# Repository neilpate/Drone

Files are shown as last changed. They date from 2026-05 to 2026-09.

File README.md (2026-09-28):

# Drone



A learning project: build a quadcopter from scratch — own hardware, own firmware, no existing flight stack.

The drone is the artefact; understanding the whole stack end-to-end is the deliverable.

## What we're building

- **Platform:** BBC micro:bit v2 (nRF52833) for Phases 1–3; custom nRF5340 PCBA for Phases 4–5.
- **Language:** Rust (`no_std`, `embassy-nrf`) on the firmware; Rust on the PC-side ground-station application too.
- **IMU:** ICM-42688-P on SPI (external; micro:bit's onboard sensor has no gyro).
- **Airframe:** quadcopter.
- **Flight stack:** rolling our own — no PX4 / ArduPilot.

See [`doc/00-vision.md`](doc/00-vision.md) for the full vision and the phased milestone plan.

## Status

**Phase 2 (advanced prototyping) in progress.** The whole stack runs on hardware. The drone has made **first free flights** — brief untethered, self-levelling hops on its own battery under closed-loop control — with telemetry over a two-hop radio link and PID gains **tuned live from the ground station and now persisted to flash** ([ADR 0025](doc/decisions/0025-persist-control-parameters-flash.md)): tune, save, power-cycle, and the gains survive.

- **Round trip, ~100 Hz, ~25–30 ms.** The `groundstation` app sends four-axis pilot commands (sliders or a gamepad) over USB-CDC to a remote micro:bit, which relays to the drone over IEEE 802.15.4 ([ADR 0014](doc/decisions/0014-radio-protocol-ieee802154.md)). Telemetry returns the same path as a high/low-rate split frame ([ADR 0027](doc/decisions/0027-split-telemetry-high-low-rate.md)), postcard + COBS framed, every buffer sized at compile time from the shared types.
- **Firmware — an Embassy task graph.** A **supervisor** failsafe ([ADR 0017](doc/decisions/0017-supervisor-failsafe-state-machine.md)) is the sole publisher of motor commands: a five-state machine with a stick arm/disarm gesture, idle auto-disarm, and loss-of-link detection within ~100 ms.
- **Sense → estimate → control.** The ICM-42688-P IMU ([ADR 0003](doc/decisions/0003-imu-icm42688-spi.md)) is read over SPI at 1 kHz; a complementary filter ([ADR 0022](doc/decisions/0022-attitude-estimation-complementary-filter.md)) gives a roll/pitch estimate; a single-loop **angle-mode PID** ([ADR 0024](doc/decisions/0024-control-law-angle-mode-pd.md)) mixes it and the pilot command into a four-motor demand. IMU zeroing is re-runnable from the ground station; every gain is a runtime message, saveable to flash.
- **Actuation + ESC telemetry.** **DShot300** drives a 4-in-1 AM32 ESC ([parts list](hardware/electrical/parts-list.md)); each ESC's **KISS serial telemetry** — RPM, pack voltage, temperature — is read back over an idle-framed UART and logged.
- **Discipline.** Frames, signs and command newtypes are fixed in [ADR 0021](doc/decisions/0021-coordinate-frames-and-command-semantics.md); the pure logic (filter, controller, supervisor, wire types) is host-tested in `firmware-drone-core`.

The ground station plots and logs every signal live, times the round trip, pushes and saves PID gains, shows a live 3D view of the drone's attitude, and pairs with an offline `analyze` tool that turns a telemetry log into a legible flight report.

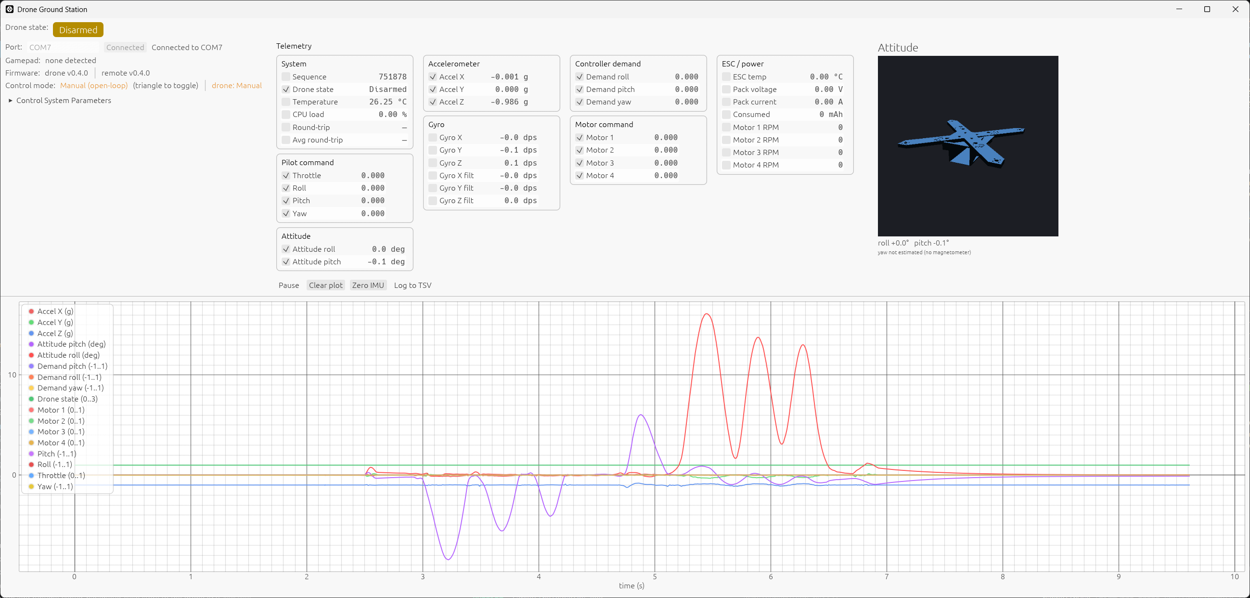
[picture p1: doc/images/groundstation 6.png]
The ground station: a live 3D view of the drone frame rotating with the estimated roll/pitch (top right), the live telemetry tables, and the multi-signal time plot below.


Recent tuning work — validating the integral term as a **centre-of-mass trim corrector**, balancing the airframe by the per-motor effort split, and re-zeroing out a one-directional drift — is consolidated into a new control-troubleshooting field guide ([doc/06-control-troubleshooting.md](doc/06-control-troubleshooting.md)).

**Next (to finish Phase 2):** rebuild on the lighter next-generation frame — the previous flight frame was retired in a lost-control crash — with the IMU mounted near the centre of mass (which should cut the estimator lag at its source) and a fresh, softer re-tune; plus a firmware **power-limit** mode and the netted test enclosure ([doc/07-safety.md](doc/07-safety.md)). In parallel, **Phase 4 is well underway** — the custom nRF5340 flight controller (`drone_fc` v2, [ADR 0026](doc/decisions/0026-phase4-custom-pcba-nrf5340.md), [ADR 0028](doc/decisions/0028-fabricate-v2-board-pcbway.md)) is fully routed with turnkey PCBA fab exports out to PCBWay; the micro:bit stays the tuning platform meanwhile.

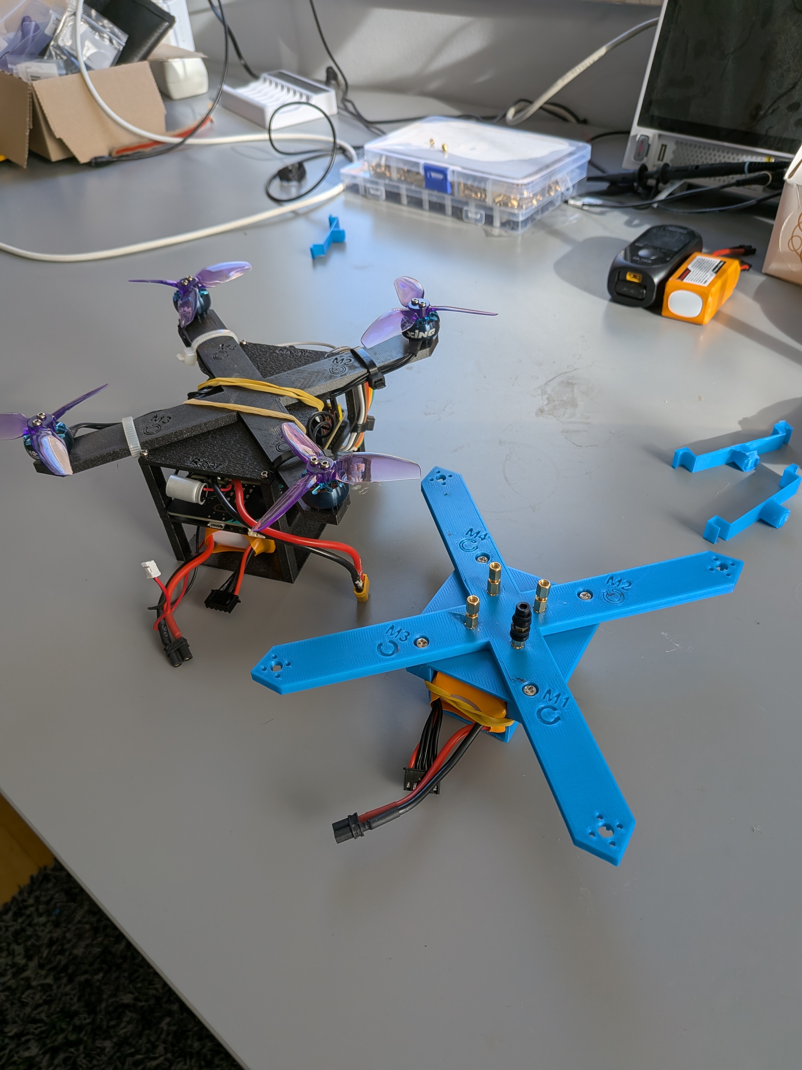
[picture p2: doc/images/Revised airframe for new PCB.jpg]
The revised 3D-printed airframe designed to carry the custom nRF5340 flight-controller PCB and ESC stack.


Schematic of the custom nRF5340 flight controller board (drone_fc v2).

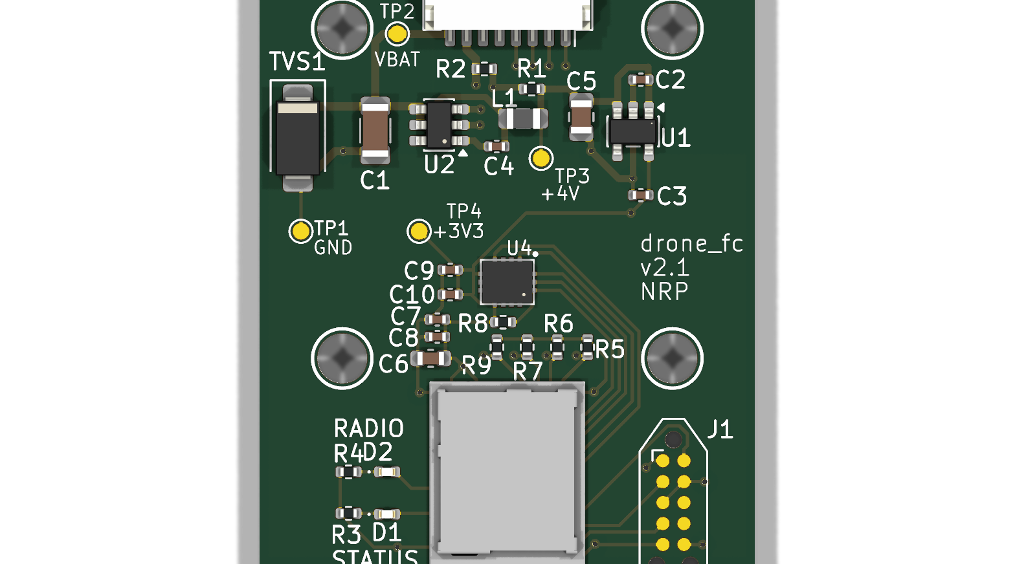
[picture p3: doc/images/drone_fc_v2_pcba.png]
Render of the custom nRF5340 flight controller PCBA (drone_fc v2).


See [`doc/progress.md`](doc/progress.md) for the dated milestone history, [`doc/dev-environment.md`](doc/dev-environment.md) for the toolchain, and [`doc/decisions/`](doc/decisions/README.md) for the full decision history.

## Repository layout

- [`AGENTS.md`](AGENTS.md) — shared context file for AI coding assistants (Copilot, Claude, etc.). Read first.
- [`crates/`](crates/README.md) — Cargo workspace. `firmware-drone-microbit` (on-target binary), `firmware-drone-shared` (board-agnostic tasks/signals), `firmware-drone-core` (host-testable logic).
- [`doc/`](doc/README.md) — design notes, vision, architecture, hardware/software/control docs.
- [`doc/02-architecture.md`](doc/02-architecture.md) — system architecture overview (two micro:bits, RF link, ground-station evolution).
- [`doc/decisions/`](doc/decisions/README.md) — Architecture Decision Records (ADRs).
- [`hardware/`](hardware/README.md) — mechanical (Fusion 360) and electrical (KiCad).

## Testing

Host-testable logic (wire types, the supervisor state machine, the ground-station helpers) is unit-tested and run with [cargo-nextest](https://nexte.st/):

```sh
cargo nextest run                                                 # workspace host crates
cargo nextest run --manifest-path crates/groundstation/Cargo.toml # the GUI crate
```

A tracked `pre-push` git hook runs the suite before every push, and [GitHub Actions](.github/workflows/ci.yml) runs `fmt` + `clippy` + tests on every push and pull request (the badge above). On-target firmware is exercised on hardware, not in CI. See [`doc/ci-and-testing.md`](doc/ci-and-testing.md) for the details and the one-time hook setup.

## Decisions so far

- [ADR 0001](doc/decisions/0001-platform-airframe-stack.md) — Real-hardware quadcopter, roll our own firmware, learning-first scope.
- [ADR 0002](doc/decisions/0002-mcu-and-language.md) — BBC micro:bit v2 + Rust for Phases 1–3.
- [ADR 0003](doc/decisions/0003-imu-icm42688-spi.md) — External IMU: ICM-42688-P on SPI.
- [ADR 0004](doc/decisions/0004-concurrency-embassy-channels.md) — Concurrency model: Embassy + channel-based actor pattern, no BSP.
- [ADR 0005](doc/decisions/0005-pc-software-language-rust.md) — PC-side software in Rust; shared `proto` crate for the wire protocol.
- [ADR 0006](doc/decisions/0006-mechanical-cad-fusion360.md) — Mechanical CAD: Fusion 360; commit `.f3d` source + `.stl` mesh (STEP dropped, amended 2026-07-09).
- [ADR 0007](doc/decisions/0007-testing-and-ci-strategy.md) — Testing and CI: unit-test everything possible, local-first feedback, `core`/`task` split, HIL deferred.
- [ADR 0008](doc/decisions/0008-repository-folder-layout.md) — Repository folder layout: `crates/`, `doc/`, `hardware/{mechanical,electrical}/`, all lowercase.
- [ADR 0009](doc/decisions/0009-workspace-bootstrap-and-crate-naming.md) — Workspace bootstrap from day one; `firmware-<role>` naming; `core`/`task` split realised as sibling crates.
- [ADR 0010](doc/decisions/0010-board-support-package.md) — Board Support Package layer: `board` module inside `firmware-drone`, Cargo-feature-selected, tasks take erased types.
- [ADR 0011](doc/decisions/0011-task-tracking-issues-and-batches.md) — Task tracking: GitHub Issues as canonical backlog, Projects board as view, labels as taxonomy, batched filing.
- [ADR 0012](doc/decisions/0012-lint-and-format-policy.md) — Lint and format policy: `main` stays `rustfmt`-clean and `clippy`-clean; suppressions require justification.
- [ADR 0013](doc/decisions/0013-async-communication-primitives.md) — Async inter-task communication: 2×2 rule over `Channel` / `Watch` / `Signal` / `PubSubChannel`.
- [ADR 0014](doc/decisions/0014-radio-protocol-ieee802154.md) — Radio link: IEEE 802.15.4 (raw PHY/MAC), channel 20.
- [ADR 0015](doc/decisions/0015-host-testing-no-std-crates.md) — Host-testable `no_std` crates: `cfg_attr(not(test), no_std)`, inline `mod tests`, `cargo test` honours `default-members`.
- [ADR 0016](doc/decisions/0016-newtype-per-physical-quantity.md) — Newtype per physical quantity for shared types: distinct newtypes per quantity, no shared `PercentageValue` base.
- [ADR 0017](doc/decisions/0017-supervisor-failsafe-state-machine.md) — Supervisor task as failsafe state machine: 4-state enum, tick-driven, pure logic in `firmware-drone-core`, supervisor is the sole publisher of motor commands.
- [ADR 0018](doc/decisions/0018-pc-link-uart-postcard-cobs.md) — PC ground-station link: USB-CDC virtual COM port to nRF52833 UART, 115 200 8N1, postcard + COBS framing (Proposed; first cut shipped with plain ASCII).
- [ADR 0019](doc/decisions/0019-airframe-class-3in-4s-printed.md) — Airframe and propulsion class: 3" ducted cinewhoop, 4S LiPo, 1507-class motors, DShot 4-in-1 ESC, fully 3D-printed PETG frame (Proposed).
- [ADR 0020](doc/decisions/0020-telemetry-aggregator-single-publisher.md) — Telemetry aggregator: a dedicated task is the sole publisher of `TelemetryState`, tick-sampling per-source `Watch`es at 100 Hz and owning frame-level fields.
- [ADR 0021](doc/decisions/0021-coordinate-frames-and-command-semantics.md) — Coordinate frames and command semantics: world NED + body FRD, right-hand sign conventions, angle (self-levelling) mode first, remote sends raw normalised stick deflections (Proposed).
- [ADR 0022](doc/decisions/0022-attitude-estimation-complementary-filter.md) — Attitude estimation: complementary filter for roll and pitch (fixed-gain accel/gyro blend); yaw stays rate-only; pure filter in `firmware-drone-core` (Proposed).
- [ADR 0023](doc/decisions/0023-motor-numbering-layout-rotation.md) — Motor numbering, layout, and rotation directions: quad-X, Betaflight numbering (M1 rear-right … M4 front-left), props-out rotation, with the derived mixer sign table (Proposed).
- [ADR 0024](doc/decisions/0024-control-law-angle-mode-pd.md) — Control law: single-loop PD per axis, angle mode for roll/pitch and rate mode for yaw, derivative on the measured gyro; a single-publisher controller stage the supervisor mixes in Armed (Proposed).
- [ADR 0025](doc/decisions/0025-persist-control-parameters-flash.md) — Persist control parameters to flash: log-structured parameter store in internal flash, disarmed-gated save-on-command from the ground station (Accepted).
- [ADR 0026](doc/decisions/0026-phase4-custom-pcba-nrf5340.md) — Phase 4 custom PCBA: nRF5340 module on a hand-designed KiCad carrier (Proposed).
- [ADR 0027](doc/decisions/0027-split-telemetry-high-low-rate.md) — Split telemetry into high-rate and low-rate frames: fast flight data + slower housekeeping (Proposed).
- [ADR 0028](doc/decisions/0028-fabricate-v2-board-pcbway.md) — Fabricate the v2 flight-controller board: turnkey PCBA on PCBWay (Proposed).

## Licence

Dual-licensed under either of:

- Apache License, Version 2.0 ([LICENSE-APACHE](LICENSE-APACHE) or <http://www.apache.org/licenses/LICENSE-2.0>)
- MIT license ([LICENSE-MIT](LICENSE-MIT) or <http://opensource.org/licenses/MIT>)

at your option.

Unless you explicitly state otherwise, any contribution intentionally submitted for inclusion in this work, as defined in the Apache-2.0 license, shall be dual-licensed as above, without any additional terms or conditions.

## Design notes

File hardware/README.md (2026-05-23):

# hardware/

Physical design files for the drone, split by engineering discipline.

- [`mechanical/`](mechanical/) — Fusion 360 sources, STEP exports, print-ready meshes ([ADR 0006](../doc/decisions/0006-mechanical-cad-fusion360.md)).
- [`electrical/`](electrical/) — KiCad schematics, board layouts, fabrication outputs for the custom nRF5340 PCBA (Phase 4 onwards).

Each subfolder has its own README with file-format and naming conventions.

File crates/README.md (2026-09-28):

# crates/

Rust workspace member crates live here.

Empty at the moment — populated when Phase 1 design lands and the first `cargo new` runs. See [doc/00-vision.md](../doc/00-vision.md) for the phase plan and [doc/dev-environment.md](../doc/dev-environment.md) for toolchain setup.

Expected initial members (subject to Phase 1 design):

- `firmware-drone-core` / `firmware-drone-shared` / `firmware-drone-microbit` — drone firmware, `core`/`task` split realised as sibling crates ([ADR 0007](../doc/decisions/0007-testing-and-ci-strategy.md), [ADR 0009](../doc/decisions/0009-workspace-bootstrap-and-crate-naming.md), [ADR 0029](../doc/decisions/0029-multi-board-firmware-shared-library.md)). **First to land.**
- `proto` — shared wire-format types ([ADR 0005](../doc/decisions/0005-pc-software-language-rust.md)).
- `firmware-ground` — ground micro:bit firmware (transparent USB ↔ radio bridge).
- `groundstation` — PC-side application ([ADR 0005](../doc/decisions/0005-pc-software-language-rust.md)).
- `xtask` — build / flash / test / lint runner ([ADR 0007](../doc/decisions/0007-testing-and-ci-strategy.md)).

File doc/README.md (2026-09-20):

# Drone Project — Documentation

This directory holds the design notes, decisions, and references for the Drone project.

## Structure

Domain docs are numbered `0N-topic.md`. Process / tooling docs are unnumbered and live alongside them. Anything marked _(not yet written)_ is a planned slot, not a stub.

- `README.md` — this file; index and conventions.
- `00-vision.md` — high-level goals: what we're building, why, and the phase plan.
- `progress.md` — reverse-chronological log of notable milestones (the dated history the README used to carry).
- `01-requirements.md` — functional and non-functional requirements. _(not yet written)_
- `02-architecture.md` — system architecture, components, data flow.
- `03-hardware.md` — hardware choices, sensors, actuators, wiring. _(not yet written)_
- `04-software-stack.md` — languages, frameworks, libraries, build setup. _(not yet written)_
- `05-communication.md` — RF link, USB, message formats, framing. _(not yet written)_
- `06-control.md` — flight control path: attitude estimation, control law, mixing, supervisor/failsafe.
- `06-control-troubleshooting.md` — companion field guide: recurring control-system symptoms, how to tell them apart in `analyze`, and what fixes each.
- `07-safety.md` — failsafes, arming, battery monitoring, bench discipline. **Prerequisite for Phase 3 free flight.**
- `ci-and-testing.md` — what is tested where, how to run the suite, and the pre-push hook (enable once per clone with `git config core.hooksPath .githooks`).
- `dev-environment.md` — toolchain setup, `probe-rs`, board labelling, two-board workflow. Windows-specific notes included.
- `decisions/` — Architecture Decision Records (ADRs), one file per decision.
- `learning/` — short notes on things I did not know before starting this project (Rust, Embassy, ARM, embedded conventions). See [learning/README.md](learning/README.md).
- `research/` — external references, datasheets, links, notes. See [research/README.md](research/README.md) for what belongs there.

Mechanical CAD files (`.f3d` source + print-ready `.stl` / `.3mf`) live under [`hardware/mechanical/`](../hardware/mechanical/) ([ADR 0006](decisions/0006-mechanical-cad-fusion360.md)). Electrical / PCBA design files live under [`hardware/electrical/`](../hardware/electrical/) (Phase 4 onwards). Rust crates live under [`crates/`](../crates/).

## Conventions

- Markdown for all docs.
- Use ADRs in `decisions/` for any non-trivial choice (format: `NNNN-title.md`).
- Keep entries dated; append rather than overwrite when capturing evolving thinking.
- Link to source files in the repo using relative paths.
- Writing style is engineering documentation, not blog prose. See `AGENTS.md` Writing style for the rules.

## Status

Vision and architecture agreed. Twenty-one ADRs in place ([decisions/](decisions/README.md)). Phase 1 bring-up in progress: firmware boots, LED heartbeat runs, BSP layer in place. Active backlog lives in [GitHub Issues](https://github.com/neilpate/Drone/issues) with a kanban view at [project #5](https://github.com/users/neilpate/projects/5) — see [ADR 0011](decisions/0011-task-tracking-issues-and-batches.md). Next firmware work: FICR.DEVICEID boot banner, board-ID refuse-to-arm, then ICM-42688 SPI bring-up once the breakout arrives.

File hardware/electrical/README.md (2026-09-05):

# hardware/electrical/

Electrical and electronic design: schematics, PCB layout, fabrication outputs, wiring diagrams.

**Primary content (Phase 4 onwards):** custom nRF5340 carrier-board PCBA — the successor to the BBC micro:bit v2 for Phases 4–5 ([ADR 0002](../../doc/decisions/0002-mcu-and-language.md)).

**Tool:** KiCad (assumed, not yet ADR'd — decision lands with the Phase 4 PCBA design ADR).

**Expected committed file types:**

- `*.kicad_pro`, `*.kicad_sch`, `*.kicad_pcb`, `*.kicad_sym`, `*.kicad_mod` — KiCad project, schematic, board, symbol library, footprint library.
- `*.step` — 3D export of the assembled board, for mechanical fit checks against `hardware/mechanical/`.
- Fabrication outputs (Gerbers, drill files, BOM, pick-and-place) under a `fab/` subfolder per board revision, generated on tag.

**Naming:** by board, e.g. `flight-controller-rev-a/`, `flight-controller-rev-b/`. New revision = new folder, never overwrite.

## v2 Module Symbol

The custom `MDBT53_P1M` symbol in [v2/drone_fc_v2_symbols.kicad_sym](v2/drone_fc_v2_symbols.kicad_sym) includes all 65 module pads, checked against the [Raytac Rev. E datasheet](../../doc/hardware/%5BnRF5340%5D%20MDBT53-1M%20%26%20MDBT53-P1M_Ver.E%20spec.pdf), section 2.5 (pages 15-18). (2026-09-05)

- U3A retains the existing wired pin positions; U3B exposes the remaining GPIO; U3C exposes the regulator connections. These are units of one physical module, not separate components.
- GPIO pins use manufacturer names and bidirectional electrical types. Application functions belong on schematic net labels, not in the library pin names. Refer to the datasheet for fixed alternate functions such as analog inputs, NFC, crystal, QSPI, and high-speed SPI.
- Every unused pad has an explicit schematic no-connect. U3C follows normal-voltage LDO mode (section 8.1.1): VDD and VDDH are tied to 3.3 V, and DCCH, DCCD, DECD, DCC, and DECR are unconnected. Firmware must not enable DC/DC without the required external circuit.
- The library and schematic copies are synchronised. All pre-existing electrical connections were preserved when completing the symbol. The PCB and manufacturing outputs were not updated; the earlier schematic LED polarity correction remains separate from the manufactured board.

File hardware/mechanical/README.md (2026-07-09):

# hardware/mechanical/

Mechanical CAD: airframe, motor mounts, sensor mounts, test enclosure, anything 3D-printed or machined.

**Tool:** Fusion 360 ([ADR 0006](../../doc/decisions/0006-mechanical-cad-fusion360.md)).

**Committed file types** (per ADR 0006):

- `*.f3d` — Fusion 360 native source. The authoritative copy.
- `*.stl` / `*.3mf` — print-ready meshes for parts that go to the printer. Mark slicer settings in the filename or a sibling note if it matters.

**Naming:** a descriptive part name with matching stems across file types. Add a `-vN` suffix if you keep multiple generations of a part, and bump it when the geometry changes meaningfully.

## Parts

| Part | Files | Notes |
| --- | --- | --- |
| Simple Motor Mount | [`.f3d`](Simple%20Motor%20Mount.f3d) (Fusion source), [`.stl`](Simple%20Motor%20Mount.stl) (print mesh) | First printed part. Flat plate carrying the iFlight XING2 1404 (M2) motor bolt pattern. |

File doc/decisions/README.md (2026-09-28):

# Architecture Decision Records

Each non-trivial design decision gets its own file here.

## Format

- Filename: `NNNN-short-kebab-title.md` (zero-padded sequential number).
- Status field at top: `Proposed` / `Accepted` / `Superseded by NNNN` / `Deprecated`.
- Structure: **Context** (why we're deciding this now), **Decision** (what we chose), **Consequences** (what this commits us to and what it rules out).
- Don't edit an accepted ADR to reverse it — write a new one that supersedes it. ADRs are append-only history.

## Index

- [0001 — Platform, airframe, and firmware approach](0001-platform-airframe-stack.md) — Accepted, 2026-05-21
- [0002 — MCU and firmware language: micro:bit v2 + Rust](0002-mcu-and-language.md) — Accepted, 2026-05-21 (amended by 0004)
- [0003 — IMU: ICM-42688-P on SPI](0003-imu-icm42688-spi.md) — Accepted, 2026-05-21
- [0004 — Concurrency model: Embassy with channel-based actor pattern](0004-concurrency-embassy-channels.md) — Accepted, 2026-05-22
- [0005 — PC-side software in Rust](0005-pc-software-language-rust.md) — Accepted, 2026-05-23
- [0006 — Mechanical CAD: Fusion 360](0006-mechanical-cad-fusion360.md) — Accepted, 2026-05-23
- [0007 — Testing and CI strategy](0007-testing-and-ci-strategy.md) — Accepted, 2026-05-23
- [0008 — Repository folder layout](0008-repository-folder-layout.md) — Accepted, 2026-05-23
- [0009 — Workspace bootstrap and crate naming](0009-workspace-bootstrap-and-crate-naming.md) — Accepted, 2026-05-23
- [0010 — Board Support Package (BSP) layer](0010-board-support-package.md) — Accepted, 2026-05-23
- [0011 — Task tracking: GitHub Issues as canonical backlog, batched filing](0011-task-tracking-issues-and-batches.md) — Accepted, 2026-05-24
- [0012 — Lint and format policy: rustfmt + clippy clean before commit](0012-lint-and-format-policy.md) — Accepted, 2026-05-24
- [0013 — Async inter-task communication: when to use Channel, Watch, Signal, PubSubChannel](0013-async-communication-primitives.md) — Accepted, 2026-05-24
- [0014 — Radio link protocol: IEEE 802.15.4 (raw PHY/MAC)](0014-radio-protocol-ieee802154.md) — Accepted, 2026-05-27
- [0015 — Host-testable `no_std` crates: wiring pattern](0015-host-testing-no-std-crates.md) — Accepted, 2026-06-01
- [0016 — Newtype per physical quantity for shared types](0016-newtype-per-physical-quantity.md) — Accepted, 2026-06-01
- [0017 — Supervisor task: failsafe state machine driving safe motor commands](0017-supervisor-failsafe-state-machine.md) — Accepted, 2026-06-02
- [0018 — PC ground-station link: USB-CDC UART, postcard + COBS](0018-pc-link-uart-postcard-cobs.md) — Proposed, 2026-06-05
- [0019 — Airframe and propulsion class: 3" ducted, 4S, fully 3D-printed frame](0019-airframe-class-3in-4s-printed.md) — Proposed, 2026-06-14
- [0020 — Telemetry aggregator: single-publisher fan-in for a multi-source struct](0020-telemetry-aggregator-single-publisher.md) — Accepted, 2026-06-20
- [0021 — Coordinate frames, attitude sign conventions, and pilot-command semantics](0021-coordinate-frames-and-command-semantics.md) — Proposed, 2026-06-21
- [0022 — Attitude estimation: complementary filter for roll and pitch](0022-attitude-estimation-complementary-filter.md) — Proposed, 2026-06-27
- [0023 — Motor numbering, layout, and rotation directions](0023-motor-numbering-layout-rotation.md) — Proposed, 2026-07-18
- [0024 — Control law: single-loop PD, angle mode roll/pitch, rate mode yaw](0024-control-law-angle-mode-pd.md) — Proposed, 2026-07-22
- [0025 — Persist control parameters to flash](0025-persist-control-parameters-flash.md) — Accepted, 2026-08-14 (implemented 2026-09-19)
- [0026 — Phase 4 custom PCBA: nRF5340 module on a hand-designed carrier](0026-phase4-custom-pcba-nrf5340.md) — Proposed, 2026-08-19
- [0027 — Split telemetry into high-rate and low-rate frames](0027-split-telemetry-high-low-rate.md) — Proposed, 2026-08-22
- [0028 — Fabricate the v2 flight-controller board (PCBWay turnkey)](0028-fabricate-v2-board-pcbway.md) — Proposed, 2026-09-03
- [0029 — Multi-board firmware: shared library plus thin per-board binaries](0029-multi-board-firmware-shared-library.md) — Accepted, 2026-09-20 (Phase 1 implemented 2026-09-28; Phase 2 pending nRF5340)

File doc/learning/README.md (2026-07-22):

# Learning notes

Short notes on things I did not know before starting this project. Rust, Embassy, ARM, embedded conventions — anything that came up during real work and was worth writing down so future-me does not have to re-derive it.

Different from `decisions/` (ADRs are project choices) and `research/` (external references). These are personal "I learned a thing" notes, scoped to topics that actually appeared while building.

## Conventions

- One topic per file. Short. Linkable.
- Lead with the question or the observation that prompted the note. Then the answer. Then optional detail.
- Compare to systems programming / C where it helps the intuition.
- Date significant additions: `(YYYY-MM-DD)`.
- File naming: `topic-name.md`, lowercase, hyphenated.

## Index

- [rust-value-semantics.md](rust-value-semantics.md) — returning values, RVO, sret, AAPCS registers, why "return by value" is free. (2026-05-30)
- [nested-result-with-timeout.md](nested-result-with-timeout.md) — `with_timeout` produces `Result<Result<T, E>, TimeoutError>`; the three-arm flat match, the peel-layer-by-layer alternative, and the `.ok()??` shortcut. (2026-05-30)
- [slices-and-arrays.md](slices-and-arrays.md) — `[T; N]` vs `[T]` vs `&[T]`; fat pointers; why slices are the answer to C's "pass an array and a length" pattern; relevance for `no_std`. (2026-05-30)
- [gpio-state-during-reset.md](gpio-state-during-reset.md) — why the motor spun during firmware flashing: GPIO is hi-Z at reset, an active-low driver with a floating input means "on"; pull-up resistors and proper enable pins as the two fixes. (2026-06-10)
- [embassy-time-and-tickless-timers.md](embassy-time-and-tickless-timers.md) — how `Timer::after_secs(1).await` actually works: compile-time `TICK_HZ`, the 32_768 Hz RTC, tickless scheduling with compare registers, multiple pending timers from one hardware register. (2026-06-16)
- [serial-uart-framing-and-gotchas.md](serial-uart-framing-and-gotchas.md) — telemetry over the serial link: packet-vs-stream framing, postcard + COBS, `CobsAccumulator`, embassy `UarteRx::read` fills the whole buffer, `serialport::try_clone` deadlocks on Windows, single-field structs are wire-identical to their field, and `Watch::get().await` stalling until the first publish (seed a safe neutral default at startup). (2026-06-19)
- [cpu-load-profiling-idle-spinner.md](cpu-load-profiling-idle-spinner.md) — measuring CPU load with no OS: a lone lowest-priority spinner of fixed work timed against the free-running RTC, `load = 1 - T0/T1`; why the spinner must be alone and never `.await`, `black_box`/`inline(never)`, defmt's missing float precision and the basis-point trick, and the cooperative-starvation cliff. (2026-06-26)
- [postcard-maxsize-sizing-buffers.md](postcard-maxsize-sizing-buffers.md) — a `SerializeBufferFull` hard-fault from a hand-picked `[0u8; 32]` buffer; deriving postcard's `MaxSize` (`experimental-derive`) to compute the worst-case serialized size at compile time, how postcard counts bytes (varint/f32/struct/enum), COBS framing overhead, and exporting one `FRAME_MAX_SIZE_BYTES` const so every buffer grows with the wire type. (2026-06-26)
- [micromath-atan2-nan-and-valid-seeds.md](micromath-atan2-nan-and-valid-seeds.md) — estimated roll came back NaN on hardware but not host: micromath's `atan2` returns NaN at the origin where std returns 0, the estimator seeded from an all-zero (physically impossible) IMU default, NaN is absorbing so it stuck forever; fix by making seed defaults physically valid (1 g down) and scrubbing NaN at the angle-newtype boundary. Host tests can't catch target-only numeric edge cases. (2026-07-21)
- [imu-vibration-and-bench-psu-power.md](imu-vibration-and-bench-psu-power.md) — the closed-loop controller looked wildly unstable on the bench, but it was the test rig, not the PID: a hard-mounted IMU turned motor vibration into gyro noise that the D-term amplified, and a bench PSU could not power the motors (foldback brownout + it cannot sink regen current, so throttle-down trips OVP and cycles the output relay). Open-loop mode isolated the plant; soft-mounting and a battery are the fixes. When a loop looks unstable, suspect the rig before the gains. (2026-07-22)

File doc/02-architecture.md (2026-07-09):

# 02 — Architecture

_Date: 2026-05-23 (open questions refreshed 2026-07-09)_
_Status: Draft — captures the agreed shape. Many sub-decisions it deferred (RF link, wire framing, failsafe, ground-station split, PC visualisation) are now settled in ADRs 0013–0022; the [Open questions](#open-questions--future-adrs) section marks which and links each._

This doc is the **map of the system**, not a specification. It describes the pieces, how they connect, and the design principles that hold the pieces together. Detailed choices (which RF protocol, which USB framing, etc.) live in [ADRs](decisions/README.md).

## Summary

- **Two BBC micro:bit v2 boards.** One on the drone (flight controller), one on the ground (link bridge + later, standalone ground station).
- **Symmetric hardware.** Same MCU, same radio peripheral, same Rust toolchain on both ends. Drivers and link-layer code are literally the same crate on both sides.
- **2.4 GHz RF link** between the two micro:bits — IEEE 802.15.4 raw PHY/MAC, channel 20 ([ADR 0014](decisions/0014-radio-protocol-ieee802154.md)).
- **Two pilot-side iterations** planned:
  - **v1 — PC-in-the-loop.** Ground micro:bit is plugged into a PC over USB. The PC also has a PlayStation-style controller plugged in. The PC handles UI, telemetry plotting, and reading the controller; the ground micro:bit is mostly a USB↔RF bridge.
  - **v2 — Standalone ground station.** No PC. The ground micro:bit (or its successor) drives an LCD and reads the controller directly.
- **Design principle:** the **on-air protocol stays the same across v1 and v2**. The drone-side firmware does not change between them. Only the ground side evolves.

## System diagram — v1 (PC-in-the-loop)

```mermaid
flowchart LR
    subgraph Pilot["Pilot side"]
        Human(["Human"])
        PS["PS controller"]
        PC["PC<br/>(control SW + telemetry UI)"]
        GBit["Ground micro:bit<br/>(USB ↔ RF bridge)"]
    end

    subgraph Air["Air side"]
        DBit["Drone micro:bit<br/>(flight controller)"]
        IMU["ICM-42688<br/>(SPI)"]
        ESC["ESCs ×4 → motors"]
    end

    Human -- hands --> PS
    PS -- USB HID --> PC
    PC -- USB CDC serial --> GBit
    GBit <-- 2.4 GHz RF --> DBit
    DBit <-- SPI --> IMU
    DBit -- PWM/DShot --> ESC
```

## System diagram — v2 (standalone ground station)

```mermaid
flowchart LR
    subgraph Pilot["Pilot side"]
        Human(["Human"])
        PS["Controller<br/>(PS or similar)"]
        GBit2["Ground micro:bit<br/>(or successor MCU)"]
        LCD["LCD"]
    end

    subgraph Air["Air side"]
        DBit2["Drone micro:bit"]
    end

    Human -- hands --> PS
    PS -- TBD --> GBit2
    GBit2 -- SPI/parallel --> LCD
    GBit2 <-- 2.4 GHz RF --> DBit2
```

The air side is **unchanged** between v1 and v2. Only the pilot-side composition differs.

## Components

### Drone micro:bit (flight controller)

The thing that flies. Responsible for:

- Sampling the IMU (INT1-driven per [ADR 0003](decisions/0003-imu-icm42688-spi.md); a fixed crystal-paced `dt` is polled for now, see [ADR 0022](decisions/0022-attitude-estimation-complementary-filter.md)).
- Sensor fusion → attitude estimate.
- Control loop (rate → angle, eventually cascaded).
- Motor mixer → 4 motor outputs.
- Receiving commands over RF.
- Sending telemetry over RF.
- Failsafe behaviour when the RF link drops.

Concurrency is the channel-based actor pattern on Embassy (see [ADR 0004](decisions/0004-concurrency-embassy-channels.md)). Each of the responsibilities above is, roughly, one `async` task with a typed inbox.

### Ground micro:bit

Sits between the operator and the drone. Its scope grows between v1 and v2:

- **v1:** USB↔RF bridge. Owns the RF link layer (framing, ACKs, sequence numbers). Forwards parsed messages up to the PC over USB. Does not parse or generate application-layer messages.
- **v2:** absorbs everything the PC was doing — controller input, UI rendering on an LCD, telemetry logging (to flash? to a card?). Same RF stack underneath.

### PC (v1 only)

Off-the-shelf desktop. Runs:

- Controller driver (SDL2 / `gilrs` / whatever Rust crate ends up sensible).
- Command-source loop: read controller state → build command message → send down USB.
- Telemetry sink: read telemetry from USB → parse → plot / log.

The PC is a **development scaffold**, not a deliverable. It exists in v1 because writing an embedded UI before flying is yak-shaving. It goes away in v2.

### Controller

A PlayStation-style gamepad. In v1 it talks USB HID to the PC. In v2 it talks to the ground micro:bit directly — *how* is a v2-era open question (USB host is non-trivial on nRF52833; Bluetooth is the more likely answer, or a different controller, or a successor MCU with USB host).

### LCD (v2 only)

For displaying flight state, battery, RSSI, mode, etc. when the PC isn't there. Specific part / interface deferred until v2 is actually being built.

## The 4-layer stack

Both micro:bits run conceptually the same layered stack. Being explicit about the layers is the lever that keeps v1→v2 cheap.

| Layer | Drone side | Ground side (v1) | Ground side (v2) |
|---|---|---|---|
| **App** | flight control, fusion, mixer, failsafe | _(none — PC owns it)_ | command source, telemetry UI |
| **Session** | command/telemetry framing, message types | same | same |
| **Link** | RF link layer (framing, ACKs, sequence numbers) | same | same |
| **Transport** | nRF radio peripheral | nRF radio peripheral | nRF radio peripheral |

**The bottom three layers are identical on both micro:bits and identical across v1 and v2.** Only the top layer differs by role and by ground-station generation. That is the architectural invariant worth protecting.

In v1, the PC effectively *is* the ground-side App layer, reached via a USB transparent pipe through the ground micro:bit.

## Data flow

### Command path (pilot → motors)

1. Pilot moves stick.
2. **v1:** PC's controller-poll loop reads HID state, builds a `Command { throttle, roll, pitch, yaw, flags }` message, sends it over USB to the ground micro:bit. **v2:** ground micro:bit reads controller directly and builds the same message.
3. Ground micro:bit's Link layer frames the message, transmits it over RF (with ACK if the link layer supports it).
4. Drone micro:bit's Link layer receives and deframes; hands the message to the Session/App layer.
5. App layer updates the latest-commanded setpoint (kept in a `Signal` or single-slot channel — *not* queued; only the latest matters).
6. The control loop (running on its own timer-driven task at the configured rate) reads the latest setpoint, runs PID, mixes, updates ESC outputs.

### Telemetry path (drone → pilot)

1. The IMU task reads a sample over SPI on a fixed `dt` tick. (INT1-driven sampling per [ADR 0003](decisions/0003-imu-icm42688-spi.md) is still the intended endpoint; a nominal crystal-paced `dt` is used for now — see [ADR 0022](decisions/0022-attitude-estimation-complementary-filter.md).)
2. Fusion task consumes samples; updates the attitude estimate.
3. Telemetry task periodically (rate TBD) builds a `Telemetry { attitude, battery, rssi, mode, … }` message.
4. Link layer frames and transmits over RF.
5. Ground micro:bit receives, deframes, **v1:** forwards over USB; **v2:** updates the LCD and any local log.

### Asymmetry to design for

- **Commands** are low-rate (~50 Hz is plenty), tiny payload, latency-sensitive, idempotent (only the latest matters).
- **Telemetry** is potentially high-rate (attitude at 100 Hz, raw IMU at up to 1 kHz if logged), variable payload, throughput-sensitive, each sample matters (for plotting / diagnosis).

These are **not** symmetric and the link layer / protocol should not pretend they are.

## Design principles

1. **Symmetric MCUs.** Same chip both ends. Same crate for everything below the App layer.
2. **Stable air protocol across v1 and v2.** The drone never knows whether a PC is on the other end. v2 is purely a ground-side change.
3. **The PC is scaffolding, not product.** Don't build PC-side features that the v2 ground station won't be able to replicate (or at least know where the seam is).
4. **Asymmetric command/telemetry channels.** Different rates, different reliability needs, different semantics. Designed in from day one.
5. **Failsafe is a property of the drone, not of the link.** The drone decides what to do when commands stop arriving. The ground station can't be trusted to "just keep sending the right thing".
6. **Static wiring.** Tasks, channels, and their capacities are known at compile time. No dynamic allocation in the flight loop. (Consistent with [ADR 0004](decisions/0004-concurrency-embassy-channels.md).)

## Open questions (→ future ADRs)

These were the sub-decisions this architecture *invited* but did not make. Many are now settled; each is marked with its ADR. Refreshed 2026-07-09.

- **PC-side visualisation framework** — _Resolved:_ **`egui` + `egui_plot`** (the DIY option), shipped in the `groundstation` crate and plotting live. Chosen for its low-friction immediate-mode UI; [`rerun.io`](https://rerun.io) stays a future option if richer robotics-shaped visualisation is wanted, but was not needed.
- **RF link protocol** — _Resolved:_ **IEEE 802.15.4** raw PHY/MAC, channel 20 ([ADR 0014](decisions/0014-radio-protocol-ieee802154.md)). ESB was the original default; 802.15.4 won — see the ADR.
- **Wire framing** — _Partly resolved:_ shared `firmware-types` message types with **postcard** encoding, **COBS-framed over the USB↔ground UART** ([ADR 0018](decisions/0018-pc-link-uart-postcard-cobs.md)) and carried in 802.15.4 frames on air. The message types are shared, but transport framing differs per hop and the ground µbit decodes/re-encodes rather than being a fully "dumb" bridge.
- **Ground-station division of labour** — _Largely settled:_ the ground/remote µbit owns the link and relays commands/telemetry; the PC owns the App layer ([ADR 0018](decisions/0018-pc-link-uart-postcard-cobs.md)). Not yet formalised as its own ADR.
- **Failsafe behaviour** — _Resolved (bench phase):_ supervisor state machine, zero-throttle on ~100 ms loss-of-link ([ADR 0017](decisions/0017-supervisor-failsafe-state-machine.md)). Flight-phase ramp/land behaviour is still open before Phase 3.
- **Latency budget** — informal target: 5–15 ms pilot stick → motor response. The **round-trip telemetry** loop already measures **~25–30 ms** on hardware; the stick→motor control-path latency is still to be measured once the control loop exists.
- **Controller interface in v2** — _Still open._ USB HID is hard on nRF52833 (no USB host). Bluetooth controller? Different controller? Successor MCU? → v2-era decision.
- **LCD choice** — _Still open._ Deferred until v2.

## What this doc does *not* decide

- Specific RF protocol.
- Specific message formats / payload layouts.
- Specific failsafe behaviour.
- Specific PC-side tooling.
- Frame, motors, ESCs, battery (covered by future ADRs / hardware doc).

## Considered and rejected

Recorded here so they don't get relitigated. If the trade-offs ever shift, supersede with an ADR.

- **ROS2 as the PC-side architecture.** Discussed 2026-05-23. Rejected because (a) `rclrs` / `r2r` are alpha-grade, so adopting ROS2 first-class would force the PC side off Rust and onto Python/C++ — directly against [ADR 0005](decisions/0005-pc-software-language-rust.md); (b) DDS is overkill for a single drone↔PC pair; (c) we'd still need a bridge node decoding our serial protocol into ROS2 topics, so the "single source of truth" win evaporates; (d) hiding the framing / dispatch layer behind a well-known abstraction undercuts the learning goal in [ADR 0001](decisions/0001-platform-airframe-stack.md). `rerun.io` covers the one genuine ROS2 win (great telemetry visualisation) without the rest.
- **Gazebo (or any simulator) as a Phase 1–2 substitute for hardware.** Discussed 2026-05-23. Rejected because real ESC quirks, real motor noise on the IMU, real RF dropouts and real timing jitter *are* what we're here to learn ([ADR 0001](decisions/0001-platform-airframe-stack.md)). Parked as an *optional* Phase 3+ tool for safe PID tuning, not part of the core path.

## Future: video subsystem (post-Phase 5)

A camera + downlink is on the roadmap as a post-flight stretch goal. The approach is deliberately **orthogonal to the flight controller**:

- **Analog camera + 5.8 GHz VTX** on the airframe, powered from the battery, radiating to a standalone 5.8 GHz receiver next to the ground station.
- **No connection to the FC.** The nRF5340 firmware is unaware of the camera's existence. The camera and VTX share only the battery and the airframe.
- **No connection to the ground micro:bit / PC.** The video receiver is its own device with its own screen. Telemetry stays on the nRF link; video stays on 5.8 GHz analog. Two independent radios on the drone, two independent receivers on the ground.

Implications for current decisions:

- **Weight and mount budget on the Phase 4 PCBA / frame.** Plan for ~10 g of camera + VTX + cabling and a front-facing camera mount. Argues for a 3″–5″ propeller class rather than the smallest possible build.
- **No software, protocol, or architectural impact** on anything in this doc. The 4-layer stack, the v1/v2 ground-station evolution, the asymmetric command/telemetry channels — all unchanged.
- **Digital HD video systems** (DJI O3, HDZero, etc.) and **DIY WiFi-based streaming** (ESP32-S3 + camera) are explicitly rejected for now as out of scope for a hobby/learning project. Analog FPV is the lowest-risk way to get a picture without overreaching.

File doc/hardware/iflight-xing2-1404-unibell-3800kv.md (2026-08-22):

# iFlight XING2 1404 Unibell 3800 KV — motor datasheet

Captured 2026-08-22. iFlight does not publish a standalone PDF for this motor; the
specifications below are the manufacturer table as listed by the retailer we
ordered from. This file is the repo's authoritative copy so the numbers survive
link rot.

- **Source:** <https://www.fpv24.com/en/iflight/iflight-xing2-1404-unibell-3800kv-fpv-motor>
- **Order ref:** IFL-X009438
- **EAN:** 4260691178198
- **Manufacturer:** Huizhou iFlight Intelligent Technology Ltd.

## Specifications

| Parameter | Value |
| --- | --- |
| Power supply | 3–4S |
| KV | 3800 |
| Configuration | 9N12P (9 stator slots, 12 magnetic poles) |
| Stator diameter | 14 mm |
| Stator length | 4 mm |
| Shaft diameter | 1.5 mm |
| Dimensions | ⌀19.9 × 13.5 mm |
| Weight | 9.1 g |
| No-load current @ 5 V | ≤ 0.47 A |
| Maximum power | 253.4 W |
| Internal resistance | 0.220 Ω |
| Maximum current | 15.84 A |

Package contents: 1× motor, 8× M2×7 screw.

## Firmware-relevant note

**9N12P → 12 poles → 6 pole pairs.** ESC telemetry reports *electrical* RPM; the
mechanical shaft RPM is electrical RPM ÷ pole pairs. This constant is used in
`ERPM::POLE_PAIRS` ([crates/firmware-types/src/erpm.rs](../../../crates/firmware-types/src/erpm.rs)):

```
mechanical_rpm = (telemetry_erpm_field × 100) ÷ 6
```

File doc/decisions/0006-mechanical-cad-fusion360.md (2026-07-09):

# ADR 0006 — Mechanical CAD: Fusion 360

- **Status:** Accepted (amended 2026-07-09 — STEP export requirement dropped; see Amendment below)
- **Date:** 2026-05-23
- **Related:** [00-vision.md](../00-vision.md), [ADR 0001](0001-platform-airframe-stack.md)

## Amendment (2026-07-09) — STL-only in repo, STEP export dropped

**This amendment supersedes every requirement below to export or commit a `.step` file.** The confirmed workflow is: model in Fusion 360, export `.stl` to print.

- **Committed per part:** the `.f3d` Fusion source plus the print-ready `.stl` (or `.3mf`). No `.step`.
- **What we give up:** the `.f3d` keeps an editable parametric source in the repo, so geometry is never lost — but re-editing now requires Fusion (or a tool that imports `.f3d`), whereas STEP would open in any CAD package. STEP was this ADR's original escape hatch against Autodesk lock-in, so dropping it is a deliberate weakening, not an oversight.
- **Why it's acceptable:** a solo hobby build, a single modeller staying on Fusion, and the committed `.stl` still lets anyone re-print the part as-is.
- **Reversible:** if broad CAD portability matters later (handing the design off, or a FreeCAD migration), re-introduce STEP exports at that point. Nothing here blocks it.

## Context

3D-printed parts appear from Phase 1 onwards: IMU mount on the micro:bit, motor-clamp bench fixture, rigid 4-motor bench mount in Phase 2, flight frame in Phase 3, custom-PCBA carrier in Phase 4, etc. We need a single CAD tool committed early so parts are interchangeable, version-controllable, and not trapped in a format we can't open later.

The user is already familiar with **Fusion 360** and has successfully modelled and printed parts before. The question is whether that familiarity is the deciding factor or whether a better-fit alternative justifies the switching cost.

Candidates considered:

- **Fusion 360.** Industry-standard hobby/prosumer parametric CAD. Free personal-use tier (with caveats; see below). User already proficient.
- **FreeCAD 1.0+.** Open source, free forever, no vendor lock-in. The 1.0 release (late 2024) finally addressed the longstanding topological-naming problem and is genuinely usable. UX still rougher than Fusion; learning curve from scratch.
- **OnShape.** Cloud-native, slick UX, free *only if all documents are public*. Acceptable for a public hobby project, awkward the moment privacy is wanted.
- **OpenSCAD.** Code-based parametric CAD. Excellent for simple geometric brackets (motor mounts, standoffs), text-files version-control beautifully, terrible for organic shapes (canopies, fairings).
- **Solidworks / Inventor / Plasticity.** Wrong cost / scope tier for a hobby project.

## Decision

- **Fusion 360** is the mechanical CAD tool for the project.
- **Source files (`.f3d`) live in the repo** alongside firmware and docs, under [`hardware/mechanical/`](../../hardware/mechanical/).
- **Every committed `.f3d` ships with an exported `.step`** alongside it. STEP is the vendor-neutral interchange format; this is our escape hatch if Autodesk's free tier becomes unworkable.
- **Print-ready `.stl` (or `.3mf`) files are also committed** for parts we've actually printed, so anyone (including future-us on a fresh machine) can re-print without re-running CAD.

## Why Fusion 360

- **Familiarity dominates.** This is a hobby learning project where the *firmware and electronics* are the learning target. CAD is a means to an end. Spending the early phases re-learning a new CAD tool would burn time on the wrong problem.
- **Successful track record.** User has already shipped working printed parts in Fusion. Known-good toolchain.
- **Mainstream format support.** STEP, STL, 3MF export. The output files are portable even if the source isn't.
- **Reasonable hobby tier.** Free personal-use license covers everything we need.

## Why not the alternatives (now)

- **FreeCAD.** Genuinely tempting on principle (open source, no vendor risk). Real cost is the learning-curve tax during exactly the phases where we want focus on firmware. Reconsider if Autodesk meaningfully degrades the free tier.
- **OnShape.** Public-documents-only restriction is a soft no for a project that may include build details we don't want indexed and republished by AI scrapers.
- **OpenSCAD.** May still appear *alongside* Fusion for trivial parametric brackets if it's the obviously-right tool for a specific part. Not the primary CAD.

## Consequences

### What this commits us to

- A [`hardware/mechanical/`](../../hardware/mechanical/) folder structure for committing CAD sources, STEP exports, and print-ready meshes. Layout decided when the first part lands.
- Committing both source (`.f3d`) and neutral (`.step`) for every meaningful part — small ongoing discipline tax, big portability win.
- A future hardware / mechanical doc (`doc/03-mechanical.md` or similar) when the parts count justifies one.

### What this rules out (for now)

- Treating CAD as out-of-scope for the repo. Parts that exist physically must exist in version control.
- Source-file lock-in. The STEP-alongside-source rule means we are never one Autodesk policy change away from losing the geometry.

### What stays open

- **Folder layout** within `hardware/mechanical/` — decided when the first part lands.
- **Slicer choice** (PrusaSlicer / OrcaSlicer / Bambu Studio / Cura) — orthogonal to CAD; printer-dependent; not worth an ADR.
- **Whether to also use OpenSCAD** for trivial parametric brackets — case-by-case, no global rule.
- **Migration plan to FreeCAD** if Autodesk's free tier becomes unworkable. The STEP exports are the contingency; the trigger and process are not pre-decided.

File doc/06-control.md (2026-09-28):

# 06 — Flight Control

_Date: 2026-08-13_
_Status: Draft — describes the control system as implemented. The governing decisions live in ADRs [0016](decisions/0016-newtype-per-physical-quantity.md), [0017](decisions/0017-supervisor-failsafe-state-machine.md), [0020](decisions/0020-telemetry-aggregator-single-publisher.md), [0021](decisions/0021-coordinate-frames-and-command-semantics.md), [0022](decisions/0022-attitude-estimation-complementary-filter.md), [0023](decisions/0023-motor-numbering-layout-rotation.md), and [0024](decisions/0024-control-law-angle-mode-pd.md)._

This doc is the map of the flight-control path: how a stick deflection and a batch of IMU samples become four motor commands. It describes the pieces and how they connect. The rationale for each choice lives in the ADRs; the numeric gains live in code.

## Summary

- Classic **sense → estimate → control → mix → actuate** cascade.
- Each stage is an independent Embassy async task communicating through `Watch` signals ([ADR 0013](decisions/0013-async-communication-primitives.md)).
- Pure math lives in [`firmware-drone-core`](../crates/firmware-drone-core/src/lib.rs) — `no_std` on target, host-testable per [ADR 0007](decisions/0007-testing-and-ci-strategy.md) / [ADR 0015](decisions/0015-host-testing-no-std-crates.md). The matching Embassy task — board-agnostic ones in [`firmware-drone-shared/src/tasks`](../crates/firmware-drone-shared/src/tasks), hardware-touching ones in the board binary — does the I/O and drives the pure logic ([ADR 0029](decisions/0029-multi-board-firmware-shared-library.md)).
- The **supervisor** state machine gates the whole path and is the sole publisher of motor commands ([ADR 0017](decisions/0017-supervisor-failsafe-state-machine.md)).
- Every gain and limit is a runtime `ControlSystemParameters` message the ground station can push live — no reflash to tune.

## Data flow

```mermaid
flowchart LR
    IMU[imu task] -->|imu_data| EST[attitude_estimator]
    IMU -->|imu_data| CTRL[control_system]
    EST -->|attitude| CTRL
    RL[remote_link] -->|pilot_command / mode / params| CTRL
    CTRL -->|controller_demand| SUP[supervisor]
    SUP -->|motor_command| MOT[motor_controller]
    MOT --> ESC[ESCs / motors]
```

## Coordinate frames and sign conventions

Per [ADR 0021](decisions/0021-coordinate-frames-and-command-semantics.md): world NED, body FRD, both right-handed and coincident when level and pointing north. Right-hand sign rules:

- **+roll** = right side down
- **+pitch** = nose up
- **+yaw** = nose right

The remote sends raw normalised stick deflections (roll/pitch/yaw in −1..+1, throttle 0..1); the drone interprets them per the active control mode, so the wire format is mode-independent.

## 1. Attitude estimation

Source: [`sensor_fusion.rs`](../crates/firmware-drone-core/src/sensor_fusion.rs), task [`attitude_estimator.rs`](../crates/firmware-drone-shared/src/tasks/attitude_estimator.rs).

A **complementary filter** ([ADR 0022](decisions/0022-attitude-estimation-complementary-filter.md)) fuses gyro and accelerometer into **roll and pitch only**. Yaw is not estimated — with no magnetometer, heading is unobservable, so yaw stays rate-controlled.

- **First sample** seeds the attitude directly from the accelerometer via `atan2`.
- **Steady state** blends a gyro-integrated prediction with the accelerometer angle:

  $$\theta = \alpha\,(\theta_{prev} + \dot{\theta}_{gyro}\,\Delta t) + (1-\alpha)\,\theta_{accel}$$

  with $\alpha = 0.998$. At a ~1 ms step this places the gyro/accel crossover near 0.8 Hz — deliberately well below the attitude-control band so airframe motion coupled into the accelerometer does not distort the estimate at the control frequency.

The task feeds a measured `dt` from an Embassy `Instant` delta.

## 2. Control law

Source: [`control_system.rs`](../crates/firmware-drone-core/src/control_system.rs), task [`control_system.rs`](../crates/firmware-drone-shared/src/tasks/control_system.rs).

A **single-loop PID per axis** (not cascaded), per [ADR 0024](decisions/0024-control-law-angle-mode-pd.md).

### Roll and pitch — angle mode

- Setpoint = stick deflection × `max_tilt_degrees`.
- Error = setpoint − estimated angle, normalised by `max_tilt_degrees`.
- **P** on the normalised error.
- **D** on the **measured gyro rate** (not the error derivative), normalised by `max_tilt_rate_degrees_per_second`. Deriving D from the measurement rather than the error avoids derivative kick on setpoint steps. The D term opposes the motion, so it carries a negative sign.
- **I** on the error, accumulated across ticks.

### Yaw — rate mode

- Setpoint = stick deflection × `max_yaw_rate_degrees_per_second`.
- Error = setpoint − gyro Z rate, normalised by `max_yaw_rate_degrees_per_second`.
- P-only by default (`kd_yaw` / `ki_yaw` default to zero). Yaw ignores attitude — it has no angle term.

### Integral and anti-windup

- The integral clamps to `MAX_INTEGRAL = 0.5`.
- It only integrates when **not saturated** and when the error sign agrees with the accumulated integral direction (conditional integration).
- It **resets to zero whenever throttle is zero**, so the integrator cannot wind up on the bench or between arms.

### Output

Throttle passes straight through. Roll/pitch/yaw leave as normalised `−1..+1` demands in a `ControllerDemand`.

### Gyro pre-filtering

Before the D term, the control-system task runs each gyro axis through a **first-order low-pass** ([`filter.rs`](../crates/firmware-drone-core/src/filter.rs)) at a 50 Hz cutoff, keeping motor-vibration noise out of the demand. The filtered IMU data is republished for telemetry.

### Control modes

Per `ControlMode` ([`control_mode.rs`](../crates/firmware-types/src/control_mode.rs)):

- **Manual** — the pilot command passes through untouched as the controller demand.
- **Stabilized** — the PID runs as described above.

## 3. Mixing

Source: [`mixer.rs`](../crates/firmware-drone-core/src/mixer.rs).

Symmetric quad-X, Betaflight motor numbering ([ADR 0023](decisions/0023-motor-numbering-layout-rotation.md)):

| Motor | Corner | Spin | Throttle | Roll (+ right down) | Pitch (+ nose up) | Yaw (+ nose right) |
|---|---|---|:---:|:---:|:---:|:---:|
| M1 | rear-right  | CCW  | + | − | − | + |
| M2 | front-right | CW | + | − | + | − |
| M3 | rear-left | CW | + | + | − | − |
| M4 | front-left  | CCW  | + | + | + | + |

Each motor output is clamped to `0..=1`. When throttle is zero, all four motors are forced to zero.

## 4. Supervisor and failsafe

Source: [`supervisor_core.rs`](../crates/firmware-drone-core/src/supervisor_core.rs), task [`supervisor.rs`](../crates/firmware-drone-shared/src/tasks/supervisor.rs).

The supervisor ([ADR 0017](decisions/0017-supervisor-failsafe-state-machine.md)) is the **sole publisher of motor commands** and gates the entire control path. It is tick-driven (10 ms `Ticker`) or command-driven.

States: `Initialising → Disarmed → Armed → Degraded → Fault`.

- **Disarmed** always outputs `MotorCommand::ZERO`, regardless of what the controller demands. A `debug_assert` in the task enforces this.
- **Arming**: throttle-zero + full-right-yaw gesture held for >500 ms, then return yaw to centre. Disarm is the mirror (throttle-zero + full-left yaw).
- **Link loss**: 10 ticks (100 ms) with no command → `Degraded`, which neutralises attitude to zero and **ramps throttle to zero over 50 ticks** so the craft does not fly on uncontrolled after losing the link.
- **Idle safety**: armed with near-zero throttle for a long window auto-disarms, so a forgotten armed drone does not stay live.

Only in `Armed` and `Degraded` does the supervisor call the mixer.

## 5. Cross-crate wiring

- **[`firmware-types`](../crates/firmware-types/src/lib.rs)** — the shared vocabulary. One newtype per physical quantity ([ADR 0016](decisions/0016-newtype-per-physical-quantity.md)): `PilotCommand`, `ControllerDemand`, `MotorCommand`, `Attitude`, `ImuData`, `ControlSystemParameters`, `ControlMode`, plus the `Command` / `RadioMessage` wire types.
- **[`remote_link` task](../crates/firmware-drone-microbit/src/tasks/remote_link.rs)** — receives IEEE 802.15.4 packets ([ADR 0014](decisions/0014-radio-protocol-ieee802154.md)), decodes `Command` variants into the `pilot_command`, `control_mode`, and `control_system_parameter` signals, and returns telemetry.
- **[`groundstation`](../crates/groundstation/src/main.rs)** — pushes `ControlSystemParameters` live, so every gain and limit is tunable at runtime with no reflash.

## Current gains

`ControlSystemParameters::default()` in [`control_system_parameters.rs`](../crates/firmware-types/src/control_system_parameters.rs) holds bring-up placeholder values, not flight-tuned:

| Parameter | Value |
|---|---|
| `kp_roll` / `kd_roll` / `ki_roll` | 0.1 / 0.01 / 0.02 |
| `kp_pitch` / `kd_pitch` / `ki_pitch` | 0.2 / 0.01 / 0.02 |
| `kp_yaw` / `kd_yaw` / `ki_yaw` | 0.3 / 0.0 / 0.0 |
| `max_tilt_degrees` | 25.0 |
| `max_tilt_rate_degrees_per_second` | 400.0 |
| `max_yaw_rate_degrees_per_second` | 180.0 |

## Open items

- **ADR 0024 vs implementation.** ADR 0024 is titled "angle-mode PD" and defers the integral term, but the code and default parameters already implement a full PID with conditional-integration anti-windup on roll/pitch. The ADR should be updated (or an amendment recorded) to match what shipped.
- **Gains are untuned.** The defaults above are bring-up values. Tuning waits on bench/flight testing ([07-safety.md](07-safety.md)).
- **Mixer sign table is unverified.** The roll/pitch/yaw signs are derived from the ADR 0021 conventions but still need bench/flight confirmation ([ADR 0023](decisions/0023-motor-numbering-layout-rotation.md)).

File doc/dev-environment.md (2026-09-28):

# Dev environment

_Status: Living document. Will grow substantially once Phase 1 bring-up begins. Today it captures the conventions and host-OS notes that need to exist before the first `cargo` command runs._

This is the practical-side companion to the architecture and ADR docs: which OS, which toolchain, how the two micro:bits are labelled and told apart, what gotchas hit on Windows specifically. Aimed at the future "stranger landing cold in the repo" (see [00-vision.md](00-vision.md) Definition of done) as much as at the author.

---

## Host OS

The author develops on **Windows 11**. The toolchain is intended to work equally well on macOS and Linux — nothing in the build pipeline is Windows-specific — but the notes below call out Windows quirks where they exist.

If a future contributor (or future self) is on Linux / macOS, most of this doc applies unchanged; the **Windows-specific** subsection is the only part to skip.

---

## Toolchain (target state)

To be installed at the start of Phase 1. Versions to be locked via `rust-toolchain.toml` once the Cargo workspace exists.

- **Rust** via [`rustup`](https://rustup.rs/) — stable channel, plus the `thumbv7em-none-eabihf` target (nRF52833 is Cortex-M4F).
- **`probe-rs`** — for flashing and `defmt` log streaming over the micro:bit's onboard DAPLink. Install via `cargo install probe-rs-tools` once the workspace lands.
- **`flip-link`** — stack-overflow protection linker for `no_std` binaries. `cargo install flip-link`.
- **`cargo-binutils`** — `cargo size`, `cargo nm` for binary inspection. Optional but useful. `cargo install cargo-binutils` + `rustup component add llvm-tools-preview`.
- **VS Code** with the `rust-analyzer` and `probe-rs.probe-rs-debugger` extensions.

The first commit that adds the Cargo workspace will also add a `rust-toolchain.toml` pinning these versions and a `.vscode/extensions.json` recommending the extensions above.

### Verified on real hardware

The above toolchain — Rust 1.95 stable, `thumbv7em-none-eabihf`, `probe-rs`, `flip-link`, `defmt`, `defmt-rtt`, `panic-probe`, the Embassy stack — has been validated end-to-end on a BBC micro:bit v2 (2026-05-23): build, flash via the on-board CMSIS-DAP probe, `defmt` log stream over RTT, and source-level debugging from VS Code via the `probe-rs.probe-rs-debugger` extension. First on-target output was the boot banner; first peripheral exercised was the 5x5 LED matrix (P0.21 row drive + P0.28 column sink, 1 Hz heartbeat).

### Source-level debugging in VS Code

The repo ships `.vscode/launch.json`, `.vscode/tasks.json`, and `.vscode/extensions.json` to make F5 a working "build, flash, attach debugger, stream `defmt`" cycle. Requirements:

- `probe-rs.probe-rs-debugger` extension installed (VS Code prompts on first open via [`.vscode/extensions.json`](../.vscode/extensions.json)).
- The same `probe-rs` CLI on `PATH` that `cargo run` uses (versions of CLI and extension should track each other — major drift breaks the DAP wire format).

What F5 does: runs the `build firmware-drone-microbit (debug)` task, then the extension flashes the resulting ELF, halts the core at the reset vector (in `cortex-m-rt`'s startup, *before* `main`), and attaches. `defmt` frames from RTT are decoded into the Debug Console with timestamps. Breakpoints are hardware breakpoints set in the Cortex-M4's FPB unit — about six are available, after which new ones silently fail to bind.

The launch config defaults to `haltAfterReset: false` on the debug profile so the firmware runs straight to your breakpoints; the release profile keeps `haltAfterReset: true` for cases where a panic at `static` init or in startup needs to be caught.

Stepping through `async` code: Embassy lowers each `async fn` into a state machine, so single-stepping over `.await` is misleading. Set breakpoints after the await, not on it.

### Windows-specific notes

- **DAPLink USB driver.** The micro:bit v2 enumerates as a CMSIS-DAP v2 device on Windows 10/11 without any driver install — WinUSB is bound automatically. If `probe-rs list` does not see the board, check Device Manager: under "Universal Serial Bus devices" there should be a "DAPLink CMSIS-DAP" entry. If it appears under "Other devices" with a yellow exclamation, install [Zadig](https://zadig.akeo.ie/) and bind WinUSB manually.
- **Line endings.** Git on Windows defaults to `core.autocrlf=true`, which rewrites `LF` to `CRLF` on checkout. This is mostly harmless but can confuse `defmt` log parsing if log lines are captured to a file and read on a different OS. Recommendation: set `core.autocrlf=input` for this repo (`git config core.autocrlf input`) so files are stored and checked out as `LF`.
- **Path length.** Cargo's `target/` directory nests deep. On older Windows installs with the 260-char `MAX_PATH` limit still active, builds can fail with cryptic I/O errors. Enable long paths: `git config --system core.longpaths true` and the Windows registry / group-policy "Enable Win32 long paths" setting.
- **Antivirus on `target/`.** Defender real-time scanning of `target/` slows incremental builds dramatically. Add `target/` (and the repo root, if you trust your own code) to Defender's exclusions: Settings → Privacy & security → Windows Security → Virus & threat protection → Exclusions.
- **Terminal.** Prefer PowerShell 7 (`pwsh`) over `cmd.exe`. The repo's conventions and any helper scripts assume PowerShell semicolons over `&&`.

---

## Board labelling convention

Multiple physically identical micro:bit v2 boards are in play (two today, possibly more later, plus the custom nRF5340 PCBA at Phase 4). Telling them apart **physically and in logs** matters more than it sounds — a flashed-the-wrong-board mistake at Phase 3 means a `flight` build running on the ground station.

### Physical labels

Every board carries a **printed sticker on the battery-pack side**, visible while the USB cable is plugged in, with:

```
DRONE-01    or    GROUND-01    or    DRONE-PCBA-01
```

Format: `ROLE-NN`, where:

- `ROLE` ∈ { `DRONE`, `GROUND`, `DRONE-PCBA` } — what the board is *currently* used as. If a board is repurposed, peel and relabel.
- `NN` — zero-padded sequence number within that role. New boards get the next number. Numbers are never reused, even after a board is retired.

Stickers go on with a permanent marker over masking tape if a printer isn't to hand. The point is unambiguity, not aesthetics.

### Logical identification (in firmware / logs)

The nRF52833 has a 64-bit factory device ID (`FICR.DEVICEID[0..1]`). The firmware reads this at boot and:

- Includes it in the boot `defmt` banner: `[boot] role=DRONE-01 deviceid=0xDEADBEEF12345678 build=tethered`.
- Sends it in the first telemetry packet so the ground station can confirm it's talking to the expected board.

A small `board_id` lookup table maps `FICR.DEVICEID` → `ROLE-NN`. Lives in firmware (a `const` array) until the board count grows past trivial, at which point it moves to a config file. Adding a new board = one line in the table + a sticker + a commit.

### Ground-station UI

The ground-station UI prominently displays:

- The connected board's `ROLE-NN` and `deviceid`.
- The build flavour (`bench` / `tethered` / `flight`, per [07-safety.md B.8](07-safety.md)).
- The power-limit state (low / full, per [07-safety.md B.9](07-safety.md)).

A mismatch between expected and actual role is a **hard refuse-to-arm** condition.

---

## Two-board workflow

Day-to-day, the author has both micro:bits plugged into the dev machine via USB (one for the drone role, one for the ground-station / remote role). `probe-rs` distinguishes them by **DAPLink serial number**, which is also on the silver shield on the back of each board.

Probe selection is baked into each firmware crate's `.cargo/config.toml`, so `cargo run` is unambiguous regardless of how many probes are connected:

```toml
# crates/firmware-drone-microbit/.cargo/config.toml
[target.thumbv7em-none-eabihf]
runner = "probe-rs run --chip nRF52833_xxAA --probe 0d28:0204:<drone-board-serial>"
```

The remote crate has the same shape with its own serial. The selector format is `<vid>:<pid>:<serial>` — `probe-rs list` prints all three.

Practical notes:

- **Workflow.** `cd crates/firmware-drone-microbit && cargo run` always flashes the drone board; `cd crates/firmware-remote && cargo run` always flashes the remote. Use two VS Code integrated terminals (right-click → Rename) so the two `defmt` log streams are obviously distinct in the panel.
- **Serials are committed.** They identify specific physical boards. If you swap which board plays which role — or move to a different machine with different boards — update the two `.cargo/config.toml` files. One-line edit each.
- **Why not env vars.** Cargo's `runner` field is passed literally to the spawned process (no shell, no `${VAR}` expansion). Env-var indirection would need a cross-platform shell wrapper. Per-crate runner with the serial baked in is simpler and survives Windows / Unix equally.
- **Never** rely on "the first probe found" — that's how you flash the wrong board.

Once `xtask` exists ([ADR 0007](decisions/0007-testing-and-ci-strategy.md)), a `cargo xtask flash --role drone` alias may replace the bare `cargo run`, but the per-crate `.cargo/config.toml` will still be the source of truth for which probe is which.

## Build flavour per phase

Maps the phases ([00-vision.md](00-vision.md)) to the Cargo feature flags defined in [07-safety.md B.8](07-safety.md):

| Phase | Drone build | Ground-station build |
|---|---|---|
| 1 | `--features bench` | n/a (Cargo feature) |
| 2 | `--features bench` (bench-restrained, no props); `--features bench` *inside the test enclosure* for full-power spin-up | n/a |
| 3 — tethered | `--features tethered` | n/a |
| 3 — free flight | `--features flight` | n/a |
| 4 | `--features bench` | n/a |
| 5 — tethered | `--features tethered` | n/a |
| 5 — free flight | `--features flight` | n/a |

Ground-station code is a separate binary on the PC and on the second micro:bit — it doesn't carry the bench/tethered/flight axis. Its build flavour question is just debug vs release.

The build script will refuse to compile if zero or more than one of `{bench, tethered, flight}` is enabled. Picking the wrong one is a safety incident waiting to happen ([07-safety.md B.8](07-safety.md)).

---

## Future additions

This doc will grow as bring-up exposes real friction. Anticipated additions:

- Exact `rust-toolchain.toml` and `Cargo.toml` workspace layout.
- `xtask` commands (build, flash, test, lint — per [ADR 0007](decisions/0007-testing-and-ci-strategy.md)).
- Pre-push hook installation steps.
- Pin map for the custom nRF5340 PCBA (Phase 4).
- Recovery procedure for a bricked board (mass-erase via `probe-rs erase`).

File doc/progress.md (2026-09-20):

# Progress log

A reverse-chronological log of notable milestones. The [README](../README.md) reflects only the current state; this file keeps the dated history so the front page stays uncluttered.

## 2026-09-20 — Drift and balance debugging; a control troubleshooting field guide; the old frame retired

A session spent chasing a persistent in-flight drift resolved into a clear picture of the control system's remaining limits — and cost the old flight frame.

**The integral, proven as a centre-of-mass trim corrector.** The recurring "it won't hold level on throttle alone" complaint was traced not to a control bug — `analyze`'s demand-vs-model reconstruction stayed at correlation +1.0000 throughout — but to the integral being geared too slow to do its job in a short hop. With centred sticks the integral clears a steady offset first-order with time constant `τ = kp/ki`; at the bring-up `ki = 0.02` that is ~7.5 s, longer than a hop, and the `throttle == 0` reset wipes it between hops. Raising `ki` to ~0.07 (τ ≈ 2 s) let the integral trim a real nose-down CoM torque within seconds — and confirmed the trim it converges to is set by the airframe's physics, not the gain: `demand_pitch` settled at the same ~+0.038 at both `ki = 0.07` and `ki = 0.12`. No slow-`ki` wallow appeared even at 0.12, so the wallow ceiling is airframe-dependent, not fixed.

**Integrator windup against the hand.** Attempting to trim the craft while cradling it in an open palm produced a lurch on release. The cause is windup: a held craft cannot null its attitude error by rotating, so the integrator accumulates against whatever tilt the hand imposes and over-winds a trim that springs the craft on release. A valid trim can only be built in free flight (or on a CoM-pivoted rig) — the standard reason real controllers freeze the integrator until airborne.

**Balancing by the motor-effort split.** With the integral honestly reflecting the imbalance, the airframe was balanced by reading the per-motor means in `analyze` — a motor works hardest under the heaviest corner — and shaving a shapeable nose ballast preferentially off the hardest corner, which attacks the fore-aft and lateral imbalance together. The front−rear split fell 0.075 → 0.047 → 0.025 and the standing `demand_pitch` 0.038 → 0.024 → 0.012 across the session; even with all nose ballast removed the bare frame stayed marginally nose-heavy. Separately, re-zeroing the IMU on a level surface removed a ~1° static estimate offset that had been parking the craft at a true bank and driving a one-directional skirt — a reminder that self-levelling holds attitude, not position, so any residual tilt translates directly into drift with nothing to arrest it.

**A control troubleshooting field guide.** The hard-won lessons — this session's and the earlier estimator-lag and limit-cycle fights — are consolidated into [06-control-troubleshooting.md](06-control-troubleshooting.md), a symptom → diagnosis → fix companion to [06-control.md](06-control.md). Each entry names the `analyze` line that distinguishes it and states plainly that the forward control maths is already proven, to head off the reflex to blame the control code.

**The old frame retired.** A final run ended in a lost-control crash that broke the airframe. Work now moves to the already-planned lighter frame with the IMU near the centre of mass — which should reduce the estimator lag at its source and, being lower-inertia, will need a fresh, softer re-tune (pull `kp` down, scale `ki` to keep τ ≈ 2 s). Nothing learned is frame-bound; it all carries onto the rebuild.

## 2026-09-19 — Control gains persist to flash

The live-tuned PID gains now survive a power cycle. Tune from the ground station, click **Save to flash**, and the values are written to the drone's internal flash; on the next boot they load automatically. This closes the slow part of the tuning loop — no more editing the compiled-in defaults and reflashing to make a tune permanent ([ADR 0025](decisions/0025-persist-control-parameters-flash.md)).

A 2-page (8 KiB) region was reserved in `memory.x` below the build-time version page, and a `ConfigStorage` BSP wrapper (per [ADR 0010](decisions/0010-board-support-package.md)) hides `sequential-storage` over the nRF `Nvmc` flash driver behind `load()` / `save()`. A new `config_manager` task reads the region at boot and publishes the result — or the compiled defaults on a fresh board — into the control-parameter watch, then saves the drone's active gains on an explicit, disarmed-gated command.

The save command surfaced a general rule, now recorded in [ADR 0013](decisions/0013-async-communication-primitives.md): a one-shot command must not ride the remote-to-drone streaming command relay, which resends the latest command every tick — the drone would re-action it ~100 times a second (here, writing to flash in a tight loop). One-shots travel instead on dedicated signals forwarded exactly once, mirroring the existing IMU-reset path. `imu_calibrate` was converted from a `Watch<bool>` to a one-shot `Signal` in the same pass, deleting its boot-seed and reset-to-false footguns.

## 2026-09-12 — Revised airframe printed, and custom flight-controller PCBA ready for fabrication

A new 3D-printed airframe iteration and the completed custom nRF5340 flight-controller hardware design reached their fabrication milestones.

**Revised airframe for the custom PCB.** A new PETG airframe was printed to prepare for the arrival of the custom flight-controller PCBA. It integrates dedicated mounting for the 20×20 mm flight-controller and ESC stack, enclosed bays for the electronics and battery, and refined duct geometry.

The revised 3D-printed airframe designed to carry the custom nRF5340 flight-controller PCB and ESC stack.

**Flight-controller v2 PCBA layout complete and committed to fabrication ([ADR 0028](decisions/0028-fabricate-v2-board-pcbway.md)).** The four-layer KiCad design for the custom flight controller (`drone_fc` v2) reached a complete, fully routed state. The design integrates the Raytac MDBT53 (nRF5340) module with an edge antenna keepout, an SPI-connected ICM-42688-P IMU centred over the 20 mm soft-mount pattern, an 8-pin JST-SH interface for the 4-in-1 ESC, an LMR50410 buck regulator with a 3.3 V LDO powered from 4S, native USB-C, and an SWD debug port. Full turnkey fabrication outputs (Gerbers, drill files, BOM, and CPL) were generated for PCBWay turnkey assembly.

Schematic of the custom nRF5340 flight controller board (drone_fc v2).

Render of the custom nRF5340 flight controller PCBA (drone_fc v2).

## 2026-08-29 — Phase 4 flight-controller layout begins

The custom nRF5340 flight-controller schematic is now ERC-clean and has a sourced BOM. Layout began in KiCad around the actual Sequre Blueson A1 20x20 mm ESC stack: the carrier uses four soft-mount holes on the matching 20 mm square, with the IMU centred over the stack. The MDBT53-P1M module is aligned to the board edge, with a four-layer no-copper keepout beneath its antenna section. The board has labelled GND, VBAT, +4V, and +3V3 test points, and a filled GND plane connected through local ground vias. Routing is underway; 30 connections remain at the end of the session. There are no electrical clearance or short-circuit DRC violations. Remaining DRC findings are silkscreen cleanup and two dangling-track warnings to resolve before fabrication review.

## 2026-08-24 — Telemetry split into high/low-rate frames, and ESC telemetry on the ground station

Yesterday's ESC serial-telemetry bring-up produced data the radio frame had no room for. Today that data reached the ground station, by splitting the drone-to-remote telemetry into two interleaved frames.

**High/low-rate frame split ([ADR 0027](decisions/0027-split-telemetry-high-low-rate.md)).** The single `Telemetry` type was already sitting on the 802.15.4 packet ceiling (~123 of ~125 usable bytes), with no room for the 31-byte ESC block. It became a tagged `TelemetryFrame { HighRate, LowRate }` enum. The **high-rate** frame (every ~10 ms round-trip) carries the flight-critical stream — raw IMU, filtered gyro, attitude, pilot command, controller demand, motor command, drone state — and drops the duplicated accelerometer the old frame wasted. The **low-rate** frame (every 10th cycle, ~10 Hz) carries housekeeping — CPU load, control mode, chip temperature, the full four-motor ESC telemetry, and the drone's *active* control gains echoed back for ground-truth logging. The aggregator stays the single publisher and now owns the interleave schedule; the remote relays whichever frame arrives; the ground station merges both into a running view so its plot, table and TSV log always see a complete row, with the low-rate columns simply updating at their slower cadence (the ADR's merge rule). A pleasant side effect of the leaner high-rate frame: the telemetry feels visibly snappier.

**ESC telemetry on the ground station.** Per-motor RPM, pack voltage, ESC temperature and consumed-mAh now appear as live plot series, table rows and TSV columns — the offline `analyze` tool is header-driven, so it kept working untouched. The ESC's current reading is discarded at the source: the AM32 shunt is uncalibrated and reads a constant ~9 A offset, which would otherwise also poison the consumed-mAh integral.

**Ground-station readout, tidied.** The flat telemetry list became labelled, fixed-width category boxes — System, Pilot command, Attitude, Accelerometer, Gyro, Controller demand, Motor command, ESC / power — stacked in vertical columns. Numeric values are right-justified in a fixed-width monospace field so a fluctuating reading no longer jitters, and the forced `+` sign was dropped.

## 2026-08-23 — DShot, the M4 asymmetry solved, first hover on the new drivetrain, and ESC serial telemetry

The weekend the motor drivetrain went digital. Outgoing **DShot300** replaced analog servo PWM — and in doing so solved a fault that had been fought for weeks; the drivetrain was retuned on the now-symmetric plant and hovered under control on DShot; and a full **ESC serial-telemetry** path was brought up for per-motor RPM, pack voltage and temperature.

**DShot, and the M4 mystery solved.** The persistent front-left (M4) thrust deficit — chased as a weak motor, a bad mount, worn props — was really **uncalibrated per-channel analog-PWM endpoints**: each ESC channel had a slightly different pulse-width-to-throttle mapping, so identical commands produced different thrust. DShot sends the same 11-bit digital value to every ESC, so the asymmetry vanished (left/right motor spread fell to ~0) the moment the protocol switched — a fault in the actuation layer, not the motor. The DShot300 driver reuses the motor driver's PWM0 + EasyDMA sequence machinery (one bit per PWM period, a looped 16-bit frame plus inter-frame gap so the ESC sees a continuous stream), with the host-tested frame encoder in `firmware-drone-core`; it became the sole motor path and analog PWM was removed. Gotchas recorded: AM32 latches its input protocol at power-up, so the ESC must be power-cycled after any PWM/DShot switch — and because AM32 self-resets on signal loss and can catch the floating-high signal pin at reboot and drop into its bootloader, the motor line wants a pull-down (or a power-cycle after each reflash).

**Retune, and the first hover on DShot.** With the plant symmetric, roll and pitch were re-tuned from scratch and settled matched at `kp` 0.15 / `kd` 0.16 / `ki` 0.02, baked into the firmware defaults so a fresh boot flies. The drone then made its **first controlled hover on the DShot drivetrain** — the highlight of the weekend, and the first flight with the front-left deficit finally gone rather than trimmed around.

**ESC serial telemetry — a bring-up in layers.** The direct measurement the earlier RPM-notch and M4 work needed is per-motor RPM, which the ESC's KISS telemetry wire carries (one-way, 115200, a 10-byte frame of temperature / voltage / current / mAh / eRPM / CRC8). Reading it cleanly meant peeling back several problems, each masking the next. The telemetry is **request-driven** — set the DShot telemetry-request bit and the ESC replies — but *holding* the bit makes AM32 re-trigger its own transmit faster than a 10-byte frame can leave the wire (~0.87 ms), corrupting its own output; the request has to be **pulsed**, one motor at a time. Even pulsed, each request yields a short **burst** of back-to-back frames with no idle gap inside it, so a fixed-length read can never align; the fix is to capture the whole burst (a 64-byte `read_until_idle`, idle-line-framed via UARTE + a spare TIMER + PPI on P0.26) and **CRC-scan** it for the one valid frame — the checksum does the alignment, and the collisions that fail it are simply dropped. Each decoded per-motor sample fans into a four-motor `ESCTelemetry` aggregate in the telemetry aggregator, and the motor task re-sends its last command on a keepalive tick so the request bit keeps flowing even at a static throttle. The result is solid **temperature, pack voltage and per-motor RPM**; current and consumed-mAh are only as trustworthy as the ESC's (evidently uncalibrated) shunt, which reads a constant offset. A [KISS telemetry frame diagram](learning/dshot-esc-telemetry-frame.svg) and the iFlight XING2 1404 [datasheet](../hardware/electrical/datasheets/iflight-xing2-1404-unibell-3800kv.md) — confirming 9N12P (12 poles, 6 pole pairs) for the eRPM to RPM conversion — were added, and [ADR 0027](decisions/0027-split-telemetry-high-low-rate.md) proposes splitting telemetry into high- and low-rate frames so the new ESC fields fit under the 802.15.4 packet ceiling.

## 2026-08-19 — Control maths verified, on-demand IMU recalibration, deeper analysis tooling, and Phase 4 kickoff

A consolidation session: no new flight, but the control path was proven correct end-to-end, a class of `Watch` first-publish bugs was cleared, the analysis tooling gained the checks to distinguish a firmware fault from a physical one, a proper test rig was built, and the custom-PCBA phase formally began.

**On-demand IMU recalibration — and two bugs behind it.** The ground station gained a **Zero IMU** button (disarmed only) that re-runs the accel/gyro calibration at any time, not just at boot. Making it actually work uncovered two independent faults. On the drone, the recalibrated offsets were captured into a `let`-shadowed binding inside an `if` block and silently discarded, so the read loop kept using the startup offsets — the telemetry never moved. On the remote, the reset was funnelled through the same `command` `Watch` as the ~100 Hz pilot-command stream, which clobbered the one-shot event before the 10 ms relay ever sampled it; it now travels as a dedicated `Signal` (single-observer event, per [ADR 0013](decisions/0013-async-communication-primitives.md)) that latches until consumed. A related **cold-boot hang** was also fixed: `Watch::get().await` blocks until a watch is *first* published, so an unseeded `imu_calibrate` (and `cpu_load`, whose only publisher is the load profiler) would park a task forever — both are now seeded at boot. The pattern is recorded so it stops recurring.

**The control maths, proven.** The `analyze` tool gained a **controller demand-vs-model** check: it reconstructs the Stabilized-mode P and D contributions from the logged attitude, filtered gyro, sticks and per-row gains, and compares them to the logged demand. P, D, and P+D all reconstruct to a correlation of **+1.0000** with machine-precision residual — the forward control path (estimate → error → PID → demand) is faithful to [ADR 0024](decisions/0024-control-law-angle-mode-pd.md), with no sign, scaling or gain bug. A separate **D-term isolation** (empirical D = logged demand − reconstructed P) confirms the derivative path as a pure-maths identity. The honest scope note stands: this verifies the forward maths only, not the estimator's accuracy, the mixer/motor path, or closed-loop stability.

**Telling a firmware fault from a physical one.** A persistent one-directional "fight" when the craft is held level, and a slow roll creep that re-zeroing only temporarily cured, prompted a **rest/drift diagnosis** in `analyze` — raw gyro bias, the attitude estimate versus the accelerometer's own gravity angle, drift slope, and temperature. A 44-second disarmed capture came back clean (drift ~0.002 °/s, gyro bias ~0.016 °/s, estimate tracking gravity to 0.06°, temperature flat), which *exonerated* the estimator and calibration at rest and pointed the creep at **motor-vibration rectification** — a dynamic, armed-only effect — rather than a static offset or thermal drift. The proper fix (RPM-tracking notch filtering) needs per-motor RPM, which is one of the drivers for the DShot work.

**A roll test rig.** To tune safely off the flight airframe, a single-axis rig that frees the roll axis was built, with the pivot on the centre of mass so gravity neither flatters nor fights the controller (a pendulum-stable rig hides instability; a neutral one shows the true closed-loop response). The rotate-and-release balance check doubles as the CoM finder.

**Phase 4 begins; two ADRs.** [ADR 0025](decisions/0025-persist-control-parameters-flash.md) commits to persisting the live-tuned `ControlSystemParameters` to internal flash (a log-structured store via `sequential-storage` over `Nvmc`, explicit disarmed-only save, default fallback), removing the reflash step from tuning and serving as a stepping stone onto the flash stack for a later OTA effort. [ADR 0026](decisions/0026-phase4-custom-pcba-nrf5340.md) commits Phase 4: the custom flight controller is built around a **pre-certified nRF5340 module** (Raytac MDBT53 class) on a hand-designed **KiCad** carrier, **turnkey-assembled** (which de-risks the QFN IMU and module joints and reopens LGA module options), using the nRF5340's **native USB-CDC** for the PC link plus an **external SWD probe** — no onboard DAPLink, collapsing the micro:bit's USB → interface-chip → UART path. A first v1 (micro:bit-era) and v2 (nRF5340, CopperPilot-generated draft) KiCad schematic were committed; the v2 draft was reviewed and flagged as not fab-ready (incomplete buck stage, sparse decoupling, unverified module/IMU pin maps).

**DShot, scoped and researched.** The next firmware step is outgoing **DShot** on the existing micro:bit, reusing the PWM + EasyDMA sequence machinery of the motor driver (a 16-entry duty table per frame, played one-shot). Its motivation is not just protocol modernity but the per-motor **eRPM telemetry** it enables — the direct measurement to settle whether M4 is genuinely weak. A [DShot bit-pattern diagram](learning/dshot-bit-pattern.svg) was added as learning material.

## 2026-08-08 — First free flight; the roll oscillation root-caused to the estimator; PID and flight-analysis tooling

The drone **flew** — first tethered hops, then its first **untethered** free flights on its own battery. Getting there meant closing the control law with an integral term, root-causing a stubborn roll oscillation that turned out to live in the *estimator* rather than the gains, and building the offline analysis tooling that made every capture legible.

**The integral term.** The angle-mode controller ([ADR 0024](decisions/0024-control-law-angle-mode-pd.md)) gained a per-axis **integral** on roll and pitch (yaw stays rate-P), turning the PD into a PID that trims out the steady-state lean P alone leaves. It is stored in *contribution units* (`I += ki · error/max_tilt · dt`, and the output adds `I` directly), which makes live `ki` retuning bumpless — changing the gain reweights only future increments, never the accumulated value. Anti-windup is conditional integration (the increment is skipped only when it would drive further into the ±`MAX_INTEGRAL` rail, so recovery is never blocked), and the integral resets to zero at zero throttle, clearing accumulated authority on the ground and at disarm. Pure logic in `firmware-drone-core` with ten new stateful tests — accumulation, saturation, unwind, idle reset, the bumpless-`ki` property, axis independence, yaw-never-integrates — and `ki_roll`/`ki_pitch` join the live gains panel.

**Root-causing the roll oscillation — it was the estimator, not the gains.** A stubborn ~3–4 Hz roll limit-cycle survived every P/D value tried. The breakthrough was a **rate-vs-angle phase** measurement added to the analyzer: angle is the integral of rate, so a gyro must lead its own attitude by +90°; the roll estimate was lagging by ~+150° — ~60° of excess phase, which turns proportional feedback into positive feedback at the oscillation frequency. The cause was the complementary filter's gyro/accel **crossover sitting at ~3.25 Hz**, right on the control band, so motion-coupled accelerometer noise distorted the estimate exactly where it mattered. Raising the filter coefficient (α 0.98 → 0.998) dropped the crossover to ~0.3 Hz; roll gyro σ fell ~5× and the ring collapsed. No gain change could have fixed it — wrong tool, wrong layer.

**Gyro-bias calibration.** Lowering the crossover exposed a latent ~0.9 deg/s **gyro bias** on pitch, which a complementary filter converts into a steady attitude offset (θ = α·b·dt/(1−α)) that grows with α — surfacing as a visible 0.3° pitch lean. The startup calibration now zeroes the **gyro bias** alongside the accelerometer offset (the gyro-bias zeroing [ADR 0022](decisions/0022-attitude-estimation-complementary-filter.md) already called for), which both removes the offset and frees α to go lower for motion rejection with no bias penalty.

**Flight-analysis tooling.** A raw capture is illegible by eye, so the ground station's `analyze` binary grew teeth: a detrended, windowed **periodogram** for the dominant oscillation frequency and amplitude per axis (with a Nyquist caveat, since the ~90 Hz telemetry cannot resolve above ~45 Hz); the **rate-vs-angle phase** cross-spectrum above; per-row **gains logging** so every capture is self-documenting; and **flight-segment isolation** — the longest sustained-throttle window pulled out and reported on its own, because a whole capture blends ground handling, aborted attempts and the throttle chop with the brief airborne time and the aggregate hides it. The ground station itself gained a **pause + box-zoom** on the live plot for inspecting a frozen snapshot.

**First flight, and the asymmetric tune.** With the estimator fixed and the integral trimming, the bench tune settled — and it **flew**, first tethered, then untethered on its own micro:bit battery. Free flight revealed what the bench (and the incidental damping of the USB tether) had hidden: roll is far livelier than pitch, because the frame is long in X with the battery along it, so I_yy ≫ I_xx and the same gains that are calm on the heavy pitch axis drive the light roll axis unstable. The fix is a **gain asymmetry to match the inertia asymmetry** — `kp_roll` softened to 0.1 while pitch stays 0.2.

**What grounded it.** The untethered hops also exposed the airframe: a persistent front-left (M4) thrust deficit the controller burns authority to trim (it survived a fresh set of props, so it is a motor/ESC/mount issue, not props), and — found last — **two cracked right-hand struts** giving the airframe flex. A non-rigid airframe violates the rigid-body assumption the whole controller rests on (thrust vectoring plus a structural resonance the loop can excite), so tuning is paused until the struts are repaired and the front-left corner is understood. Real progress all the same: it flies, both axes hold attitude in the air, and the tooling now reads every hop honestly — the remaining work is mechanical.

## 2026-08-05 — Arming, runtime gain tuning, a gyro D-term filter, and airframe v3

Three strands landed together: a real arm/disarm sequence, live gain tuning from the ground station, and the D-term noise filter that makes closed-loop tuning viable — plus the third airframe iteration.

**Arming and disarming.** The supervisor state machine ([ADR 0017](decisions/0017-supervisor-failsafe-state-machine.md)) gained an explicit `Disarmed` state between `Initialising` and `Armed`, replacing the previous behaviour of arming on the first command received. Arming now takes a deliberate two-phase stick gesture — throttle held at zero with yaw full-right for ~500 ms, then yaw returned to centre — so the motors cannot spin the instant a packet arrives. Disarming mirrors it (throttle zero, yaw full-left) and reacts immediately. `Degraded` (loss-of-link) now recovers to `Disarmed` on a zero-throttle command rather than re-arming directly, and a safety timeout auto-disarms after 100 s of idle throttle so the craft can't sit armed unattended. The mixer short-circuits to zero motors whenever throttle is zero, and a `debug_assert` in the supervisor task enforces the invariant that a `Disarmed` state never emits a non-zero motor command. A coloured drone-state badge on the ground station makes the current state unmissable.

**Runtime gain tuning.** Reflashing to change a gain is a dead end, so the PD gains and limits became a runtime message. The ground-station-to-drone wire type was refactored from the flat `GroundstationCommand` into a `Command` enum (`PilotCommand` / `ControlModeUpdate` / `ControlSystemParameterUpdate`), carried over the radio inside a new `RadioMessage { sequence_count, command }` — moving the sequence counter out of `PilotCommand` (a transport concern) and the control mode into its own occasional message rather than riding every stick frame. The ground station gained a collapsible gains panel: sliders for every gain and limit and a "Send to drone" button that pushes a parameter update live. The drone routes each `Command` variant to its own `Watch` signal; the control loop reads the latest parameters every tick. Because the remote resends the last value each 10 ms until the sticks next move, a parameter update is naturally retransmitted a few times — implicit acknowledgement on a lossy link, for free.

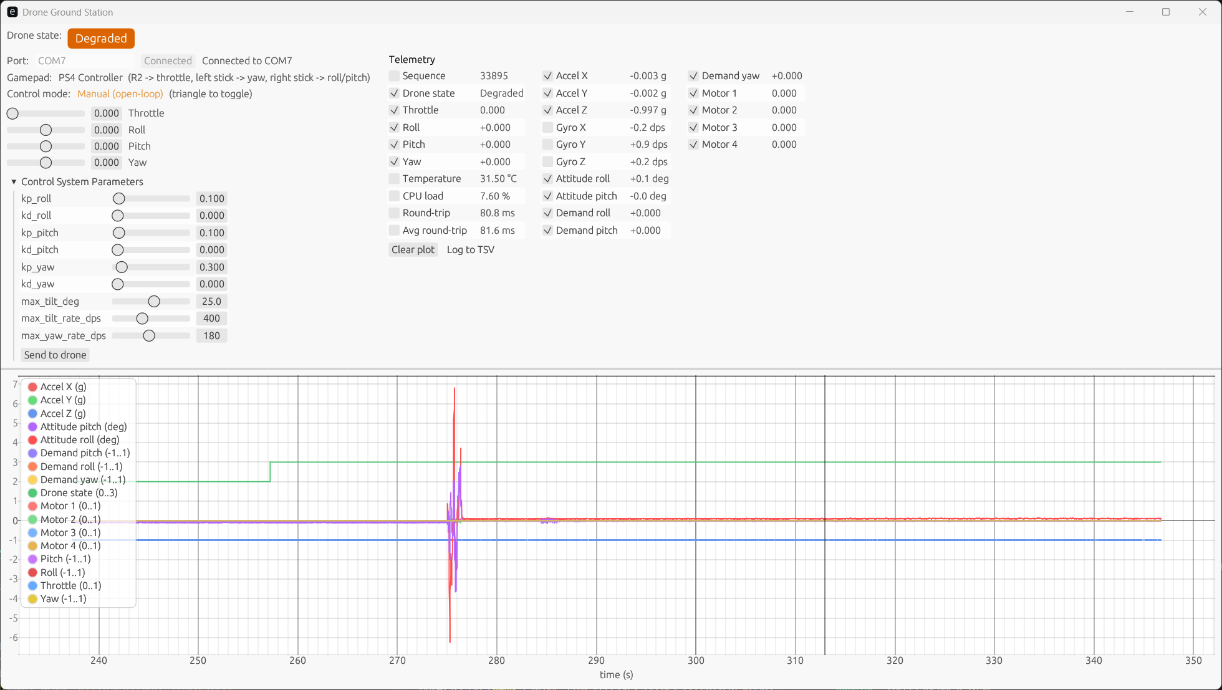
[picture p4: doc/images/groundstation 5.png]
Ground station gains panel: the Control System Parameters section expanded with sliders for kp/kd on each axis and the tilt/rate limits, a Send-to-drone button, and the coloured drone-state badge above the live telemetry plot.


**Gyro D-term low-pass filter.** Closed-loop runs were rough because the D term differentiates the gyro, amplifying motor-vibration noise into the motor command. A first-order PT1 filter (pure, host-tested in `firmware-drone-core` — seven tests covering DC gain, monotonic step response, Nyquist attenuation and an exact hand-derived sample) now filters each gyro axis before it reaches the controller, in the control-loop task so the attitude estimator keeps its unfiltered gyro (filtering there would add lag to the estimate). Cutoff is 100 Hz against the confirmed 1 ms (1 kHz) sensor cadence. The starting default gains were also made sane: the D-normalisation rate was 20 dps (absurdly twitchy) and is now 400 dps; yaw rate limit went from 20 to 180 dps; a conservative `kd` of 0.05 replaces the old 0.4.

**Airframe v3.** The third printed airframe iteration packages the build sensibly — a base for the LiPo, provision for a removable lid, and a proper IMU mount, with the IMU soft-mounted on adhesive putty for vibration isolation (the mount rigidity and squareness matter more than the damping, since a skewed mount is a static attitude bias).

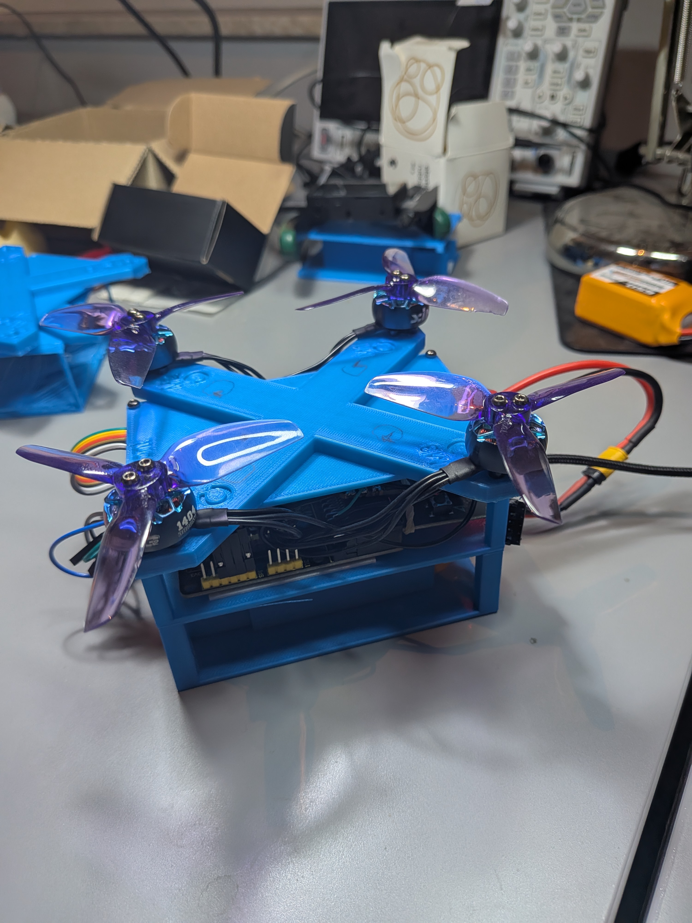
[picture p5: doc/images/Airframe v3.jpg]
The third-iteration 3D-printed airframe, packaging the battery, electronics and a soft-mounted IMU more sensibly than the earlier open frame.


The previous ground-station view this entry supersedes, before the gains panel and state badge:

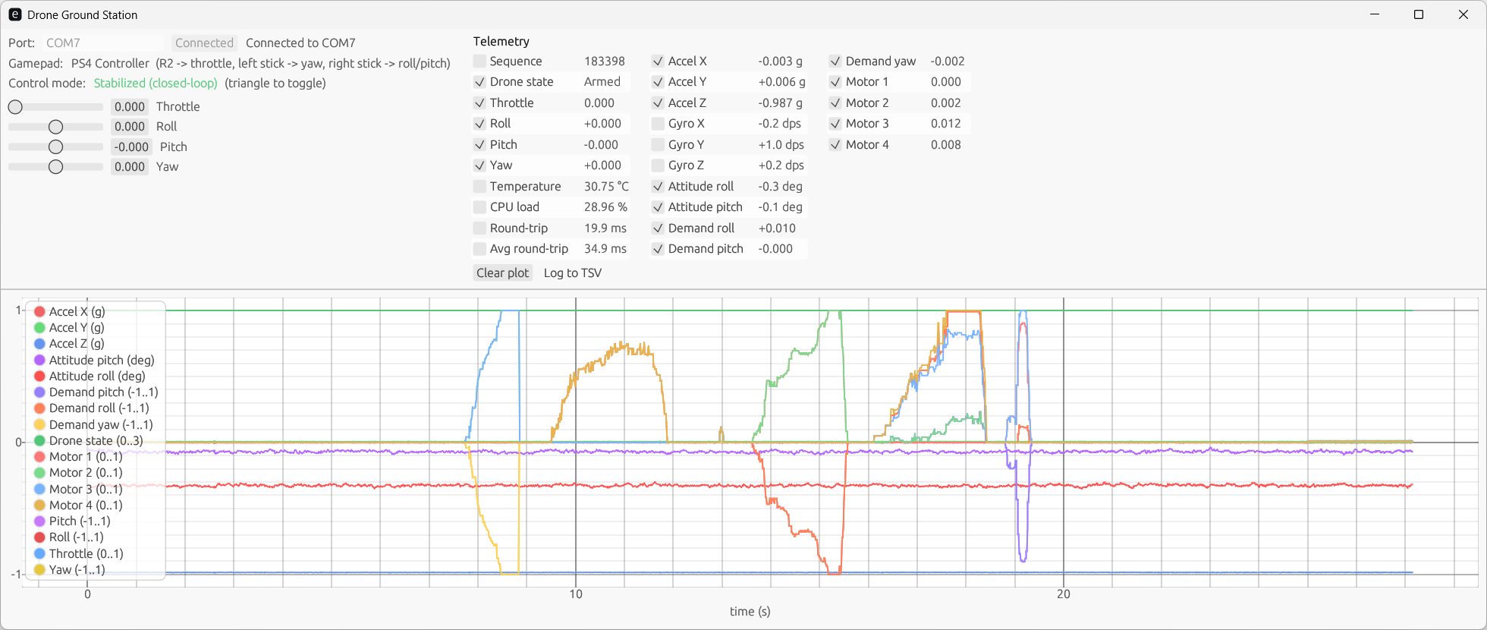
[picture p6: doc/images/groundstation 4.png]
Ground station: live telemetry plot and table showing pilot command, IMU, attitude estimate, controller demand and the four motor outputs, with the Stabilized/Manual control-mode toggle.


## 2026-07-28 — First complete quad airframe, and accelerometer level calibration

The airframe became a **quad**. The single motor-mount plate grew into the first complete 3D-printed quad-X frame — the in-house PETG design of [ADR 0019](decisions/0019-airframe-class-3in-4s-printed.md) — carrying all four iFlight XING2 1404 motors, with a two-tier body housing the micro:bit and the 4-in-1 ESC below the motor deck and the [ADR 0023](decisions/0023-motor-numbering-layout-rotation.md) motor numbering and props-out rotation directions marked on it by hand.

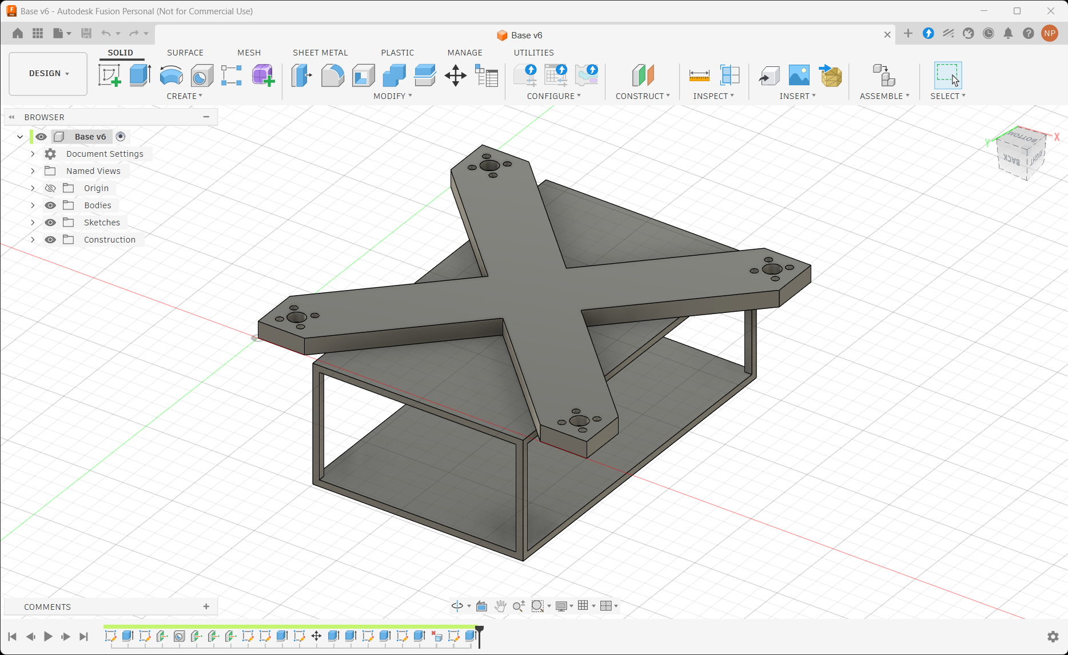
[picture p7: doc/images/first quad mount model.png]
Fusion 360 model of the quad-X frame: an X-shaped top plate with a motor-mount boss and bolt pattern at each of the four arm ends, over an open rectangular body that houses the electronics.


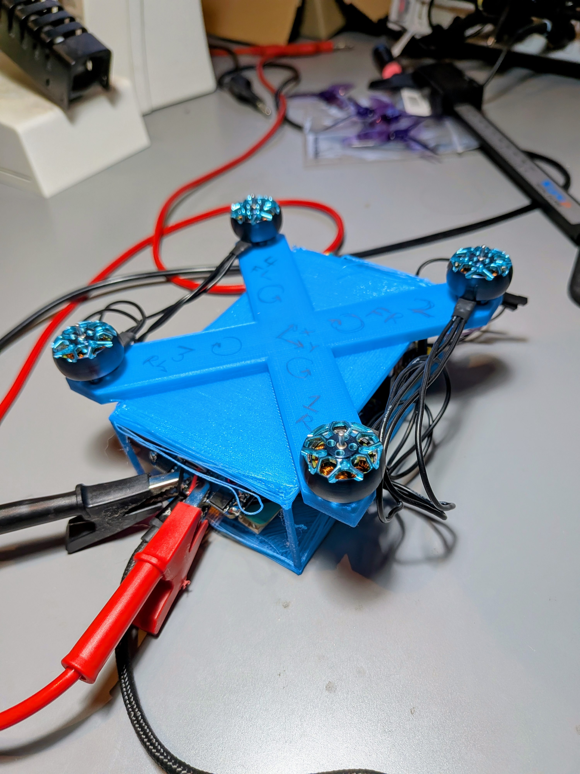
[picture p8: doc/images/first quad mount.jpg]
The first complete 3D-printed quad-X airframe: all four iFlight XING2 1404 motors mounted on a blue printed frame, no propellers, hand-marked with motor numbers and rotation arrows, wired to a bench power supply.


On the firmware side, the IMU task gained a **startup accelerometer calibration** that zeroes the sensor's mounting misalignment at the source. It averages ~100 resting accel samples at boot, then subtracts the resulting X/Y offset from every published sample — leaving Z (gravity) untouched, since zeroing the gravity axis would delete the estimator's only down-reference. A resting capture on this build measured the mount at roughly +0.09 g / −0.06 g (≈ +3.1° roll, +5.1° pitch); correcting it at the source means the estimator, controller, and telemetry all agree that a level craft reads zero. The offset is a typed `Acceleration` (a new `Sub` impl, per [ADR 0016](decisions/0016-newtype-per-physical-quantity.md)), and calibration reads retry on error rather than panicking. The same resting capture confirmed a pristine motors-off noise floor (accel σ ≈ 0.9 mg, gyro σ ≈ 0.04 dps), the direct evidence that the earlier closed-loop instability was motor vibration and bench-PSU power, not the sensor — both written up in [imu-vibration-and-bench-psu-power.md](learning/imu-vibration-and-bench-psu-power.md).

## 2026-07-22 — Control loop closed: angle-mode PD, mode toggle, and a bench-rig reckoning

The loop is **closed**. A single-loop PD controller ([ADR 0024](decisions/0024-control-law-angle-mode-pd.md)) turns the attitude estimate and pilot command into the mixer's roll/pitch/yaw demand — angle mode on roll/pitch (stick sets a target tilt against the estimate), rate mode on yaw (stick sets a turn rate against the gyro), derivative on the measured gyro rate to avoid kick, per-axis error normalised so `KP`/`KD` are dimensionless. It is a pure `control_system` function in `firmware-drone-core` (host-tested for signs, damping, axis independence and saturation), driven by a single-publisher stage that owns a `ControllerDemand` `Watch`; the supervisor mixes that demand while Armed and overrides it in the failsafe states, replacing the earlier raw-stick passthrough. That last change rippled into the supervisor's `step` signature and its whole test suite (Armed now mixes the controller demand, not the pilot command).

A remote **control-mode toggle** rides alongside it: a new `ControlMode { Manual, Stabilized }` on both `GroundstationCommand` and `PilotCommand`, flipped by the gamepad's triangle button, switches the drone between closed-loop (Stabilized) and open-loop raw-stick passthrough (Manual). Manual mode exists mostly as a diagnostic — it exercises the plant with the loop broken. To see inside the loop, the telemetry frame gained the `ControllerDemand` and the four mixed `MotorCommand` outputs, both plotted live on the ground station next to the attitude and raw IMU traces.

Wiring that telemetry surfaced a latent bug of exactly the kind [postcard-maxsize-sizing-buffers.md](learning/postcard-maxsize-sizing-buffers.md) warns about: the ground station's receive `CobsAccumulator` was hard-coded to 64 bytes while every other buffer sized itself from the shared `FRAME_MAX_SIZE_BYTES` const. The old frame was ~62 B — one field from the edge — so adding the controller demand tipped it over and the ground station silently dropped **every** frame (an over-full accumulator never emits a decode). Fixed by sizing it from the const, and the two remaining hand-picked command buffers were hardened the same way so the class of bug is closed.

Then the first real closed-loop bench run went sideways — and the lesson was that the newest code (the PID) was **not** the culprit. The instability was the test rig: a hard-mounted IMU fed motor vibration into the gyro (amplified by the D term into noisy demand), and a bench PSU could not power the motors — brownout under load, plus it cannot sink the motors' regenerative current, so every throttle-down tripped its over-voltage protection and cycled the output relay, rebooting the ESC. Manual mode proved the mixer and motor mapping were correct throughout. Both gremlins are written up in [imu-vibration-and-bench-psu-power.md](learning/imu-vibration-and-bench-psu-power.md); the fixes (soft-mount the IMU, run the motors off a battery) wait on parts — the LiPos were never ordered. Gains are untuned until the rig is sound.

## 2026-07-21 — Attitude estimate: complementary filter, fused and plotted

The IMU's six axes are now fused into a live roll/pitch **attitude estimate**. A complementary filter — a fixed-gain blend that high-passes the gyro (smooth but drift-prone) and low-passes the accelerometer (noisy but absolute) — runs as a pure, host-tested type in `firmware-drone-core`, driven by a single-publisher `attitude_estimator` Embassy stage per [ADR 0022](decisions/0022-attitude-estimation-complementary-filter.md). The stage reads the IMU `Watch` (`changed()`-paced, off the IMU's fixed-cadence `Ticker`), steps the filter with a `dt` measured from `Instant` deltas, seeds from the accelerometer on the first sample (no startup slew), and publishes an `Attitude` (roll/pitch angle newtypes, degrees) that the telemetry aggregator samples and sends back. The ground station plots it in degrees: tilt the drone by hand and the fused traces track the tilt — smooth and drift-free — next to the raw accel (noisy) and gyro (drifting), showing what the fusion buys. Angles are held in degrees end to end (the gyro reads deg/s, so the prediction step needs no unit conversion); the `atan2` sign conventions are FRD-native to match the specific-force reading (`az = −1 g` when level).

Two bugs made the trip instructive, both written up. The estimate seeded **NaN on hardware but not in host tests**: micromath's `atan2` returns NaN at the origin where std returns 0, and the IMU's all-zero startup default fed it a zero-length gravity vector; fixed by making the default a physically valid level reading and scrubbing NaN at the angle-newtype boundary ([micromath-atan2-nan-and-valid-seeds.md](learning/micromath-atan2-nan-and-valid-seeds.md)). Separately, changing the `Telemetry` wire format silently broke the ground station until the drone was reflashed — and surfaced that the workspace-excluded `groundstation` crate is never compiled by `cargo --workspace`, so a shared-type rename can land committed-but-broken there.

Also this stretch: the axis command newtypes were renamed `Roll`/`Pitch`/`Yaw`/`Throttle` → `RollCommand`/… to read distinctly from the new `*Angle` estimate types; the X-quad motor mixer and a loss-of-link failsafe ladder ([ADR 0023](decisions/0023-motor-numbering-layout-rotation.md), [ADR 0017](decisions/0017-supervisor-failsafe-state-machine.md)) went into the supervisor; and a bench session nailed down the motor wiring (an as-built 180° channel reversal, corrected in firmware) and the IMU mount orientation. The control loop is still open — the estimate feeds telemetry only; a PID between it and the mixer is next.

## 2026-07-09 — First printed part: motor mount plate

The airframe starts to exist in CAD. `Simple Motor Mount` is a flat plate carrying the iFlight XING2 1404 (M2) motor bolt pattern, modelled in Fusion 360 ([ADR 0006](decisions/0006-mechanical-cad-fusion360.md)). Both the `.f3d` Fusion source and the `.stl` print mesh are committed under [hardware/mechanical/](../hardware/mechanical/README.md), so the design is editable from the repo rather than stranded in the Fusion cloud — the durability point ADR 0006 exists to protect. We commit the `.f3d` source and `.stl` mesh only; the STEP export requirement was dropped in an [ADR 0006 amendment](decisions/0006-mechanical-cad-fusion360.md) (Fusion is the single CAD tool, so STL-to-print is the whole workflow).

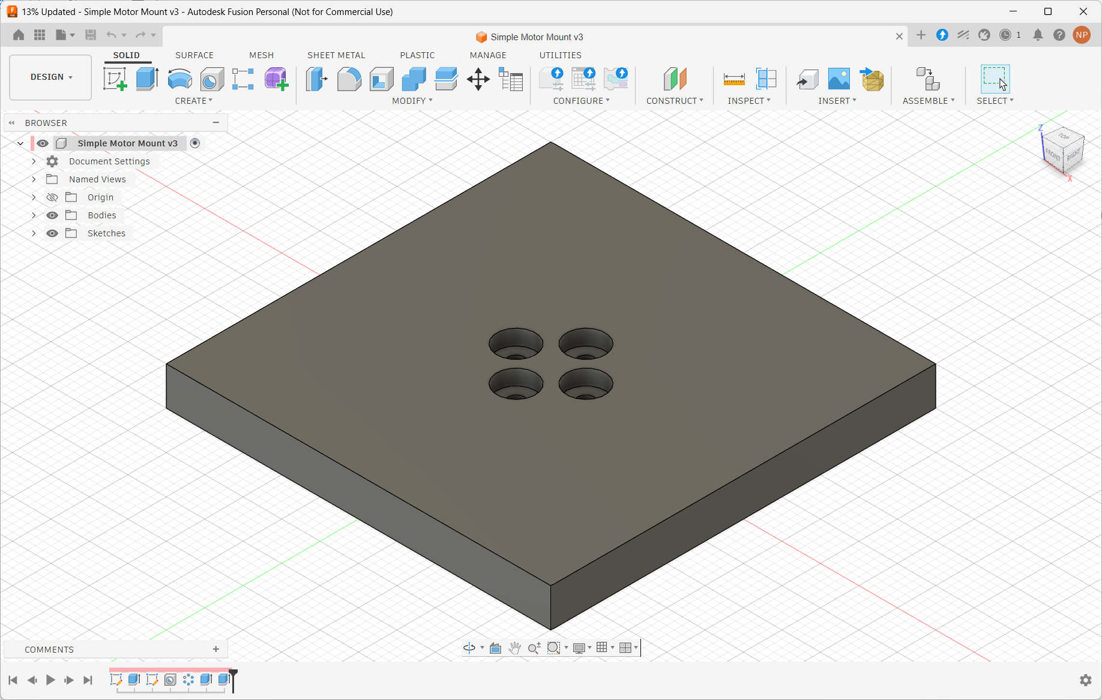
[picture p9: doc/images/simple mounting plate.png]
Fusion 360 model of the Simple Motor Mount: a square plate with four countersunk M2 holes for the motor bolt pattern.


## 2026-07-09 — Brushless ESC bring-up: non-blocking 400 Hz servo PWM

The motor output moved from a brushed motor on an H-bridge to a real brushless ESC. The four PWM0 channels now emit standard RC servo-PWM — a 1–2 ms pulse encoding 0–100 % throttle — at a 400 Hz frame, feeding a Sequre Blueson A1 (AM32) 4-in-1 ESC and an iFlight XING2 1404 brushless motor ([parts list](../hardware/electrical/parts-list.md)). 400 Hz is the practical ceiling for 1–2 ms servo PWM: the frame has to clear the 2 ms maximum pulse plus a low gap, so ~490 Hz is the hard edge and 500 Hz would leave no gap at full throttle.

Getting there meant replacing the motor driver wholesale. The first cut used embassy-nrf's `SimplePwm`, whose `set_duty` busy-waits a full PWM period whenever the peripheral is enabled — and `SimplePwm` enables at construction. At a 20 ms (50 Hz) frame those waits, running in the four `set_duty` calls inside `Board::new`, blocked for ~80 ms before a single task was spawned, so every task appeared not to start. The fix was `SequencePwm` in infinite-loop mode: EasyDMA loops over a `static [AtomicU16; 4]` duty buffer forever, and `set_throttle` does one non-blocking atomic store that the DMA reads at the next period boundary, so the CPU is never parked mid-frame. The single `unsafe` — handing the atomic buffer to the driver as a `&[u16]` — is contained and documented; the embassy examples only cover one-shot or PPI-toggled sequences, not continuous in-place duty updates, so this is a small extension of the sanctioned patterns.

On the scope the signal is clean: ~1 ms idle pulse, ~2 ms at full throttle, steady 400 Hz frames, with the pulse width correctly independent of the frame period. At boot every channel holds a zero-width (motors-off) pulse until commanded.

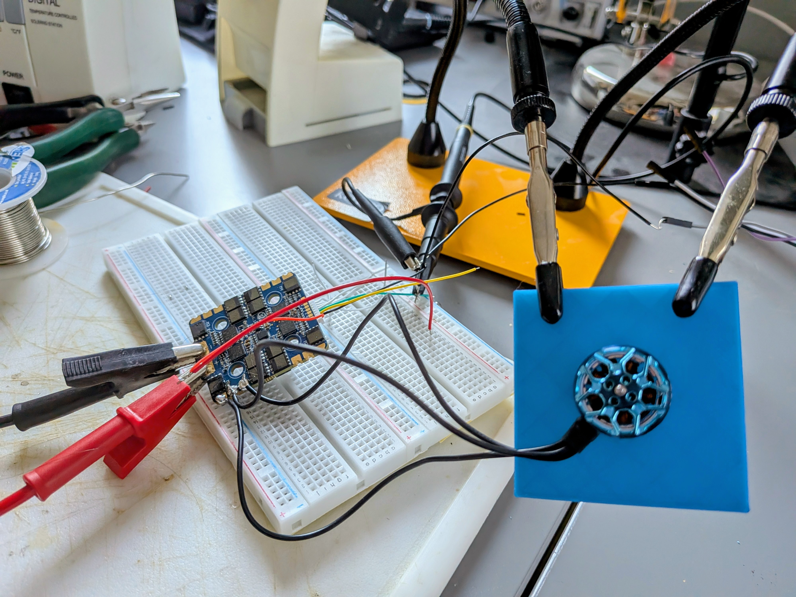
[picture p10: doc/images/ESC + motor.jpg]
Bench bring-up: the Sequre Blueson A1 4-in-1 ESC wired to an iFlight XING2 brushless motor, driven by the drone micro:bit's 400 Hz servo-PWM output.


## 2026-06-27 — IMU bring-up, six-axis telemetry, four motors validated

The drone gained its primary sense of orientation. The ICM-42688-P ([ADR 0003](decisions/0003-imu-icm42688-spi.md)) is now driven over SPI from the BSP: a manual chip-select with `transfer_in_place` register access, a WHO_AM_I identity check, power-up via `PWR_MGMT0` (accelerometer and gyroscope in low-noise mode), then a 12-byte burst read from `ACCEL_DATA_X1` that yields all six axes in one transaction. The raw `i16`s are scaled to physical units — g and deg/s — and carried as `Acceleration` / `AngularRate` newtypes inside a new `ImuData`, telemetered through the existing aggregator and surfaced on the ground station, which now plots the three accelerometer traces live alongside the command axes (gyro opt-in) and tabulates all six. On the bench the accelerometer reads ~1 g on whichever axis faces down and the gyro tracks rotation, confirming both scaling and sign.

The four-motor output path was also validated end-to-end: all of `Motor0`–`Motor3` on PWM0 (`P0.10 / P0.09 / P0.12 / P0.02`) spin on the correct corner, defaulting to off at boot through the inverted-duty convention. The ground station picked up some quality-of-life polish too — it now persists the configured serial port and auto-connects on launch (eframe storage).

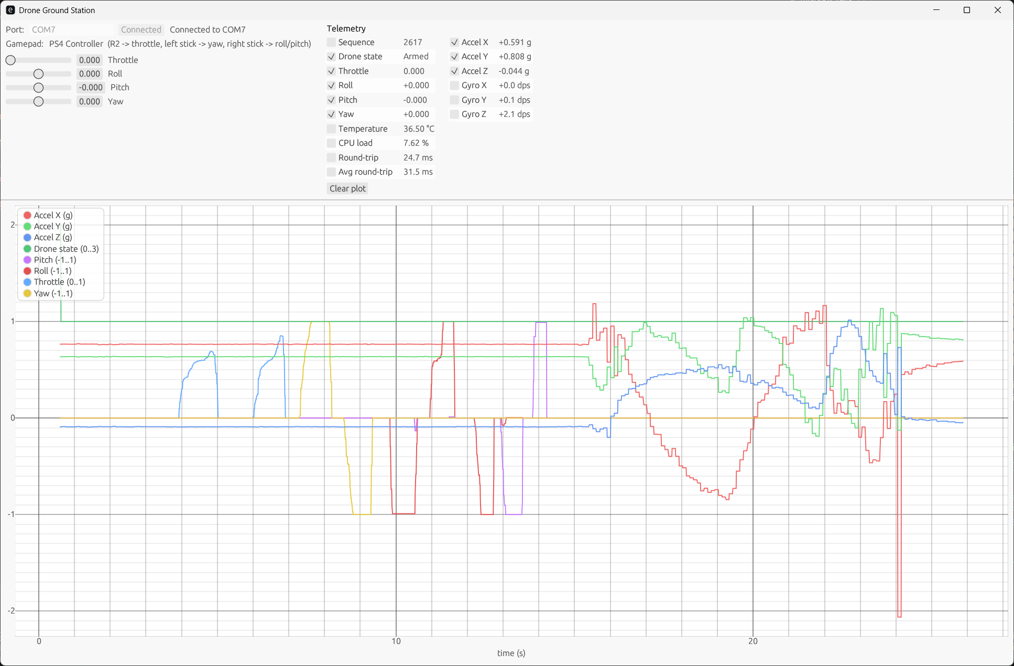
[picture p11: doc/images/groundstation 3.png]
Ground station live plot: throttle, roll, pitch and yaw command traces driven by a PlayStation gamepad alongside the matching on-screen sliders, plus the drone's live IMU accelerometer traces.


## 2026-06-26 — CPU-load profiler, and a postcard buffer-overflow fix it exposed

The drone gained a CPU-load measurement with no OS to ask. A sole lowest-priority, thread-mode `load_profiler` task busy-spins a fixed, calibrated chunk of work and infers system load from how much that window stretches under preemption (`load = 1 − T0/T1`); the result rides in each telemetry frame and is plotted by the ground station. The method, its sharp edges (the spinner must be alone and never `.await`, `black_box`/`inline(never)` to stop the optimiser, defmt's missing float precision and the basis-point trick, the cooperative-starvation cliff) are written up in [cpu-load-profiling-idle-spinner.md](learning/cpu-load-profiling-idle-spinner.md).

Adding the `cpu_load` field to `Telemetry` then surfaced a latent fault: the serialized frame outgrew a hand-picked `[0u8; 32]` buffer and `to_slice_cobs(...).unwrap()` hard-faulted the remote mid-link. It was intermittent because postcard varint-encodes the `u32` sequence number — the frame fit at boot and only overflowed once the counter widened at runtime. Fixed by deriving postcard's `MaxSize` on the wire types and sizing every TX/RX buffer from compile-time `FRAME_MAX_SIZE_BYTES` consts, so a new wire field now grows every buffer automatically. Written up in [postcard-maxsize-sizing-buffers.md](learning/postcard-maxsize-sizing-buffers.md).
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

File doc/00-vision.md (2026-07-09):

# 00 — Vision

_Date: 2026-05-21_

## What we're building

A **working quadcopter built from scratch**, on real hardware, running firmware we wrote ourselves.

## Why

The drone is the **vehicle for learning**, not the end product. The goal is to understand the *entire* stack end-to-end, from electrons to autonomous behaviour, by building each layer ourselves rather than configuring an existing one.

Concretely, by the time we're done we want to deeply understand:

- **Sensors** — how an IMU works, what raw gyro/accel data actually looks like, why it needs filtering.
- **Sensor fusion** — how noisy 3-axis gyro + accel data becomes a stable orientation estimate (complementary filter → Mahony → maybe EKF).
- **Control theory in practice** — PID loops, why tuning is hard, why cascaded loops (rate → angle) exist.
- **Motor mixing** — how three desired torques + a thrust command become four motor outputs.
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

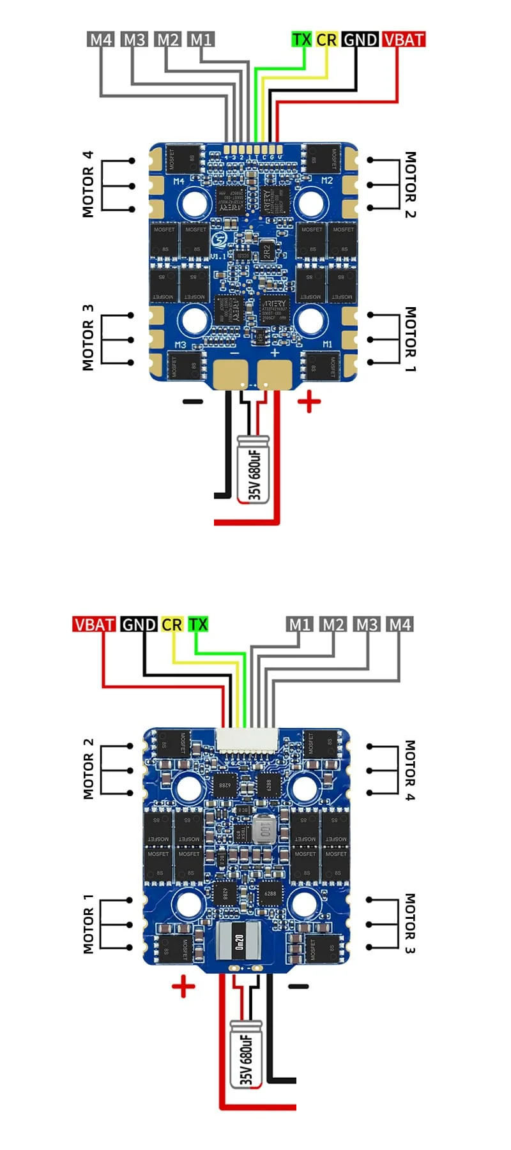
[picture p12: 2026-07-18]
doc/hardware/blueson-a1-en-long.jpg

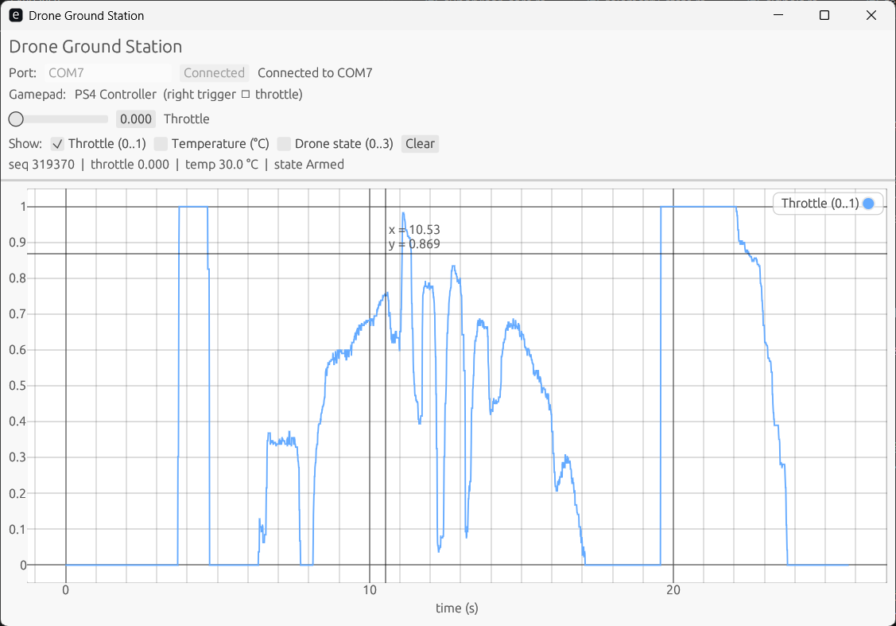
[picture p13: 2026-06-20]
doc/images/groundstation 1.png

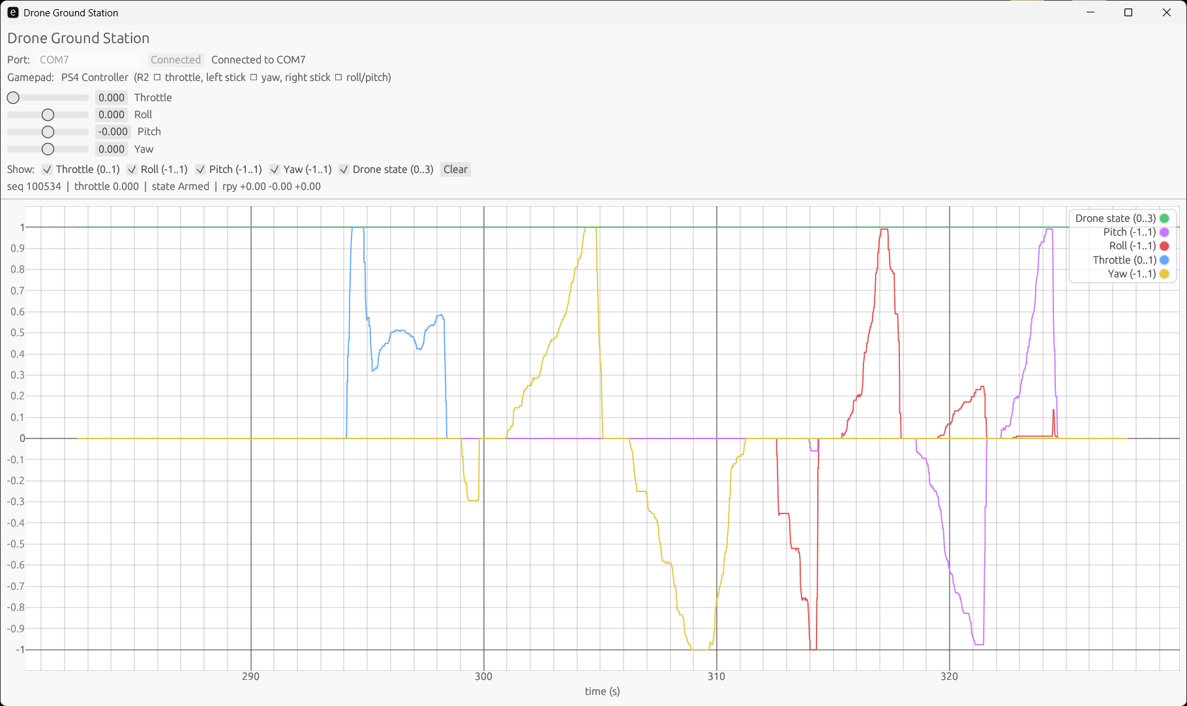
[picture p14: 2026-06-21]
doc/images/groundstation 2.png

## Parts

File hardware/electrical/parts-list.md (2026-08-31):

# Flight hardware parts list

The committed bill of materials for the first flight airframe. This realises the
class decision in [ADR 0019](../../doc/decisions/0019-airframe-class-3in-4s-printed.md):
3" ducted, 4S, 1507-class / ~3500–3800 KV motors, 4-in-1 DShot ESC. Per that ADR,
specific part numbers live here as a parts-list update, not as a new ADR. Deviations
from the class spec are called out below and tracked back to the ADR.

All propulsion parts ordered from [FPV24](https://www.fpv24.com/) (DE) in one round
on 2026-06-28.

## What this round buys, and why only this

This is the **props-off motor bring-up** round, not a fly-away round. It buys the three
propulsion parts and nothing else, because everything else needed to spin a motor on the
bench is already owned or printed:

- **Flight controller** — BBC micro:bit v2, already owned ([ADR 0002](../../doc/decisions/0002-mcu-and-language.md)).
- **micro:bit edge-connector breakout** — already owned (currently used to wire the IMU and a test motor).
- **Power for bring-up** — bench PSU, already owned. Props-off, unloaded motors draw little; a
  5–10 A bench supply is sufficient. Props-on tethered hover is *not* in scope for this round
  (see "Deferred" below) — that draws tens of amps and needs the flight battery.
- **Frame** — 3D-printed PETG, in-house design ([ADR 0019](../../doc/decisions/0019-airframe-class-3in-4s-printed.md)),
  printed not bought.

## Propulsion (ordered 2026-06-28, FPV24)

| Part | Selection | Qty | Unit | Line |
| --- | --- | --- | ---: | ---: |
| Motor | iFlight XING2 1404 Unibell 3800 KV | 4 | €16.90 | €67.60 |
| Propeller | HQ Durable 3030 (T3X3X3), tri-blade PC | 3 sets | €2.89 | €8.67 |
| ESC | Sequre Blueson A1 65 A 6S AM32 4-in-1 | 1 | €35.90 | €35.90 |
| | | | **Total** | **€112.17** |

### Motor — iFlight XING2 1404 Unibell 3800 KV

- **Link:** <https://www.fpv24.com/en/iflight/iflight-xing2-1404-unibell-3800kv-fpv-motor> (order ref `IFL-X009438`)
- **Key specs:** 1404 stator, 3800 KV, 3–4S, 9.1 g, 1.5 mm bare prop shaft (press-fit), 9N12P.
- **Why:** 3800 KV sits squarely in the ADR 0019 ~3500–3800 KV band for 3"/4S. The Unibell
  bell is a single moulded piece (one fewer fastener to lose). Press-fit 1.5 mm shaft pairs
  directly with the HQ 3030 prop below.
- **Deviation from ADR 0019:** the ADR specifies a **1507-class** stator; this is a **1404**
  (smaller). Accepted — see the ADR amendment note for 2026-06-28. Thrust budget remains ample
  for the ~200 g AUW target (T:W comfortably > 2:1), and the lighter motor only helps the AUW
  ceiling the ADR sets (~280 g / T:W 1.8 before the class is reconsidered).

### Propeller — HQ Durable 3030 (T3X3X3)

- **Link:** <https://www.fpv24.com/en/hqprop/hq-durable-prop-3030-triple-blade-t3x3x3-purple-4-pieces-pc-fpv-propeller-3-inch> (order ref `HQP-T3X3X3LU-PC`)
- **Key specs:** 3" diameter, 3" pitch, tri-blade, polycarbonate (durable compound),
  press-fit bore (1.9/1.4/1.9 mm) matching the 1.5 mm motor shaft.
- **Why:** 3"/tri-blade matches the ADR 0019 prop class. The "Durable" PC compound flexes rather
  than shatters on impact — the right choice for a learner build that will crash repeatedly during
  PID tuning. Three sets ordered for spares.
- **Naming note:** the leading **T** in `T3X3X3` denotes **tri-blade**, not a mount type. The
  motors include the M2 screws used to bolt the *motor* to the frame; the prop itself is press-fit,
  no prop screw.

### ESC — Sequre Blueson A1 65 A 6S AM32 4-in-1

- **Link:** <https://www.fpv24.com/en/sequre/sequre-blueson-a1-65a-6s-am32-esc> (order ref `SEQ-BLUESON-A1-6S-65A-AM32`)
- **Key specs:** 4-in-1, AM32 firmware, AT32F421 MCU, 2–6S (4S mid-range), 65 A continuous,
  20×20 mm mount, 19 g, current sensor. Ships with wire harness, capacitor, soft-mount grommets,
  and an XT60 lead.
- **Why:** 4-in-1 and DShot-capable as ADR 0019 requires. **AM32** is open-source firmware and,
  critically for this project, supports **standard PWM (1000–2000 µs)** as well as DShot300/600 —
  which keeps the planned PWM-first-then-DShot bring-up path open (start with the simple, forgiving
  protocol on the nRF52 PWM peripheral, switch the same board to DShot later). 65 A on 4S is well
  over-specced for four 1404s, giving thermal headroom in a poorly-ventilated printed frame.
- **No BEC.** This board has **no 5 V regulator output**. That is fine on the bench (the micro:bit
  runs from USB), but a separate switching 5 V BEC will be needed before any untethered flight. See
  "Deferred".
- **Deviation from ADR 0019:** the ADR class spec is 25–35 A; this is 65 A. Higher current rating
  is harmless headroom, not a class violation — the constraint was a *minimum* capability.
- **Naming gotcha:** the product name contains no "4-in-1", but the spec table confirms it is one.
  Earlier in selection a T-Motor F35A was briefly mis-read as a 4-in-1 (it is a *single* ESC). Lesson
  recorded: verify the product page's type field, never trust the model name alone.

#### FC connector pinout (8-pin JST-SH)

The ESC-to-FC harness is an 8-pin **JST SH** assembly. Board side is `SM08B-SRSS-TB`
(side-entry / right-angle SMT header, 1.0 mm pitch; the top-entry sibling is `BM08B-SRSS-TB`);
the cable housing is `SHR-08V-S-B`.

**This is not the standard 4-in-1 pinout.** The `ESC_4in1_Connector` schematic symbol's pin
numbering was deliberately **reversed** to match this project's custom cable, so pin 1 is the
motor end, not the power end:

| Pin | Signal | Harness wire |
| ---: | --- | --- |
| 1 | M4 | white |
| 2 | M3 | white |
| 3 | M2 | white |
| 4 | M1 | white |
| 5 | Telemetry (serial) | green |
| 6 | Current sense (analog) | yellow |
| 7 | GND | black |
| 8 | VBAT | red |

**Read the wire colours, not the pad order.** The four motor lines are all white and the pad
silkscreen is only legible from one side of the ESC, so any judgement based on "left" or "right"
depends on which face you are looking at — that mirroring already caused one false conclusion
while drawing the schematic. The colours are viewpoint-independent; the pin numbers are not.
Definitive check before fab: continuity from the ESC battery pad through the harness to the free
connector identifies pin 8 (VBAT) unambiguously.

Getting this reversed puts pack voltage (up to 16.8 V on 4S) onto an MCU GPIO. Compare
[ADR 0023](../../doc/decisions/0023-motor-numbering-layout-rotation.md), where reversed ESC signal
leads silently inverted roll and pitch; on the custom PCBA the same class of error is destructive
rather than merely confusing.

#### ESC options considered and rejected

- **T-Motor Velox V45A Lite 4-in-1** — <https://droneshop.nl/tmotor-velox-v45a-lite-4in1-esc>
  (€52.95, droneshop.nl). BLHeli_S. Rejected: separate vendor (split shipping) and pricier for no
  PWM-path advantage over AM32.
- **iFlight Borg 60RS** — <https://www.fpv24.com/en/iflight/iflight-borg-60rs-esc> (€56.90, FPV24).
  BLHeli_32, 9.5 g. Rejected: uses an **FPC ribbon connector** designed to mate with a stacked iFlight
  flight controller — awkward to hand-wire to a micro:bit; rated **4–8S** (4S is its floor, it is built
  for 5–8S); lists only DShot/OneShot/Multishot, **no standard PWM**, which closes the easy bring-up
  path. Its advantages (light, bidirectional DShot) are things this project does not need.

## Already owned (not purchased)

- **Flight controller:** BBC micro:bit v2 (×2 — second is the ground-station / remote placeholder).
- **micro:bit edge-connector breakout** — used today for IMU + test-motor wiring.
- **Bench PSU** — powers the ESC battery pads (~14.8 V, current-limited) during props-off bring-up.

## Bench bring-up notes (props OFF)

- ESC battery pads ← bench PSU set to ~14.8 V (4S nominal), current-limited.
- micro:bit ← USB from the PC.
- **Tie ESC ground and micro:bit ground together** — the motor signal wires need a common ground
  reference or the DShot/PWM signal is meaningless.
- **Always props-off on the bench.** Props go on only inside a tethered enclosure once the firmware
  is trusted (Phase 2 safety prerequisite).

## Flight battery and charging (selected 2026-07-26, FPV24)

The props-on power round: the flight battery, a charger, and the connector rework needed to mate
them to the ESC. This is the step a bench PSU cannot do — it browns out under motor load and cannot
sink the motors' regenerative current, tripping its over-voltage protection (recorded in the
learning note [imu-vibration-and-bench-psu-power.md](../../doc/learning/imu-vibration-and-bench-psu-power.md)).
Realises the battery class from [ADR 0019](../../doc/decisions/0019-airframe-class-3in-4s-printed.md).

| Part | Selection | Qty | Unit |
| --- | --- | --- | ---: |
| Battery | CNHL MiniStar 4S 650 mAh 70C (XT30U) | 2–3 | €12.50 |
| Charger | ToolkitRC M4 Pocket 1–4S 5A 80W (RTC-TK11800) | 1 | €32.90 |

### Battery — CNHL MiniStar 4S 650 mAh 70C (XT30U)

- **Link:** <https://www.fpv24.com/en/cnhl/cnhl-ministar-lipo-battery-650mah-148v-4s-70c-xt30u>
- **Key specs:** 4S (14.8 V nominal), 650 mAh, 70C, XT30U connector, ~72 g.
- **Why:** top of the ADR 0019 450–650 mAh band for the most loiter time to observe behaviour during
  PID tuning; 70C (≈45 A continuous) covers the gentle hover current of a ~200 g craft with headroom
  for tuning-burst transients. XT30 is the correct connector for this current/weight class (see the
  connector note below). Two or three packs so a charging pack never blocks a bench session.

### Charger — ToolkitRC M4 Pocket 1–4S 5A 80W

- **Link:** <https://www.fpv24.com/en/toolkitrc/toolkitrc-m4-pocket-lipo-1-4s-5a-charger-dc-7-25v-usb-c>
- **Key specs:** 1–4S balance charge, 1–5 A / 80 W, 400 mA balancer, output **XT30 & XT60**, input
  **XT60 (7–25 V)** or **USB-C PD (5–20 V)**, 75 g.
- **Why:** 1–4S matches the 4S-only platform exactly (no wasted 6S capability); the native **XT30
  output** mates the CNHL packs with no charge-lead adapter; the **USB-C PD input** lets it charge
  from a laptop/phone PD brick, or it can run off the existing bench PSU via its XT60 input. 80 W / 5 A
  is ample for a 650 mAh pack (1C = 0.65 A). Preferred over a bigger 6S charger (e.g. SkyRC B6neo)
  precisely because it is 4S-native, XT30-native, and USB-C-powerable.
- **Still needed alongside:** a **LiPo-safe charging/storage bag** (fire-safety prerequisite), and —
  if powering the charger from the bench PSU rather than USB-C PD — a bench-PSU → XT60 input lead.

### Connector note — ESC pigtail XT60 → XT30

The Blueson A1 ESC ships with an **XT60** pigtail, but the battery class is **XT30** (lighter, and
correctly sized for a 3"/4S whoop's current). Plan: **re-terminate the ESC pigtail to XT30** so it
mates the packs directly. Interim option for bench use: an XT30↔XT60 adapter lead. Do not buy XT60
packs to match the pigtail — XT60 is oversized for this class.

## Deferred (until untethered / free flight)

Not bought yet. Needed only once the build moves from tethered to free flight:

- **5 V switching BEC** — the Blueson A1 has no BEC. A buck (switching, not linear) BEC rated for
  ≥4S input is needed to power the micro:bit from the pack in untethered flight.

## References

- [ADR 0019](../../doc/decisions/0019-airframe-class-3in-4s-printed.md) — airframe and propulsion class (parent decision).
- [ADR 0002](../../doc/decisions/0002-mcu-and-language.md) — micro:bit v2 as flight controller for Phases 1–3.
- [hardware/mechanical/](../mechanical/) — the 3D-printed frame design (to be created).

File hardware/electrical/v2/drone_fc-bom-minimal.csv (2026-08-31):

Comment | Designator | Footprint
10uF | C1 | C_1206_3216Metric
1uF | C2,C3 | C_0402_1005Metric
100nF | C4,C7,C8,C9 | C_0402_1005Metric
22uF | C5 | C_0805_2012Metric
4.7uF | C6 | C_0603_1608Metric
10nF | C10 | C_0402_1005Metric
Green_Status | D1 | LED_0402_1005Metric
Blue_Radio | D2 | LED_0402_1005Metric
Cortex_SWD_10P | J1 | Tag-Connect_TC2050-IDC-NL_2x05_P1.27mm_Vertical
ESC_4IN1_JST_SH | J2 | JST_SH_SM08B-SRSS-TB_1x08-1MP_P1.00mm_Horizontal
15uH | L1 | L_0805_2012Metric
66.5K | R1 | R_0402_1005Metric
22.1K | R2 | R_0402_1005Metric
1k | R3,R4 | R_0402_1005Metric
10k | R5,R6,R7,R8,R9 | R_0402_1005Metric
SMAJ24A | TVS1 | D_SMA
TLV75533PDBVR | U1 | SOT-23-5
LMR50410_Buck | U2 | SOT-23-6
MDBT53-P1M | U3 | MDBT53-P1M
ICM-42688-P | U4 | LGA-14_2.5x3.0mm_P0.5mm_ICM42688P

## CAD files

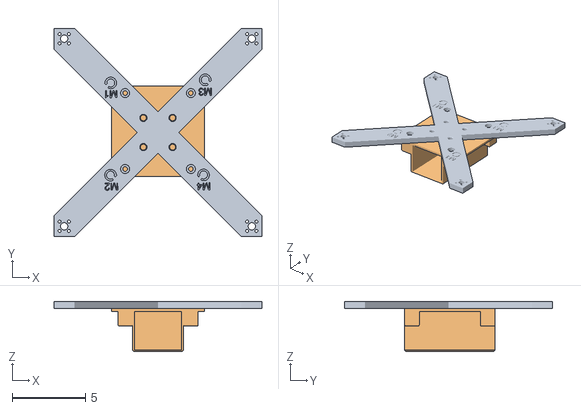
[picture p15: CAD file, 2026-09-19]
crates/groundstation/assets/flight-frame.obj
14.2 x 14.2 x 3.45
Arms
Battery Holder

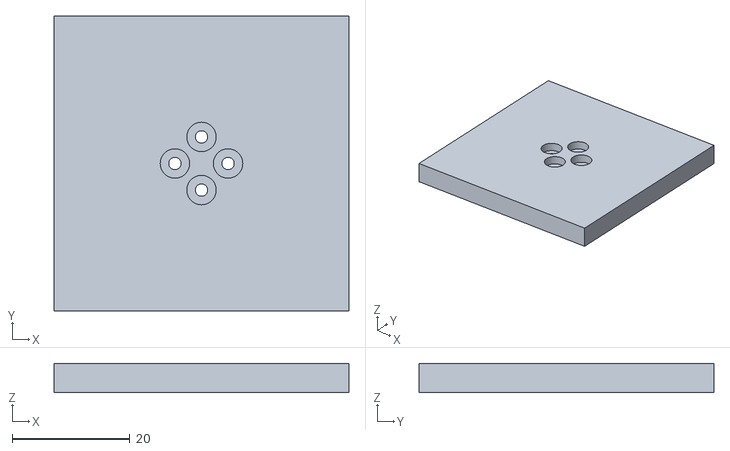
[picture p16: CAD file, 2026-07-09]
hardware/mechanical/Simple Motor Mount.stl
50.0 x 50.0 x 5.00

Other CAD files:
hardware/mechanical/Simple Motor Mount.f3d

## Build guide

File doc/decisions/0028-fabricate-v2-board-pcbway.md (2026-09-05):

# ADR 0028 — Fabricate the v2 flight-controller board (PCBWay turnkey)

- **Status:** Proposed
- **Date:** 2026-09-03
- **Related:** [ADR 0026](0026-phase4-custom-pcba-nrf5340.md) (the platform-level decision this executes — module vs silicon, SWD, DShot, turnkey assembly, no LFXO; **this ADR supersedes 0026's Aisler vendor selection**), [ADR 0003](0003-imu-icm42688-spi.md) (IMU on the board), [ADR 0014](0014-radio-protocol-ieee802154.md) (radio the module carries), [ADR 0019](0019-airframe-class-3in-4s-printed.md) (4S the board powers from), [ADR 0002](0002-mcu-and-language.md) (micro:bit → nRF5340 migration this advances)

## Context

[ADR 0026](0026-phase4-custom-pcba-nrf5340.md) fixed the platform-level choices for the Phase 4 flight controller: a pre-certified nRF5340 module on a hand-designed carrier, SWD for debug, DShot for the ESC, turnkey assembly, and no fitted LFXO. It deliberately did not commit to fabricating a specific board — schematic, layout, vendor logistics, and quantities were left to design time.

That design work has since happened. The board is laid out in KiCad as `drone_fc` **v2** under [hardware/electrical/v2/](../../hardware/electrical/v2/): a Raytac MDBT53 (nRF5340, PCB antenna) module, an ICM-42688-P IMU on SPI, an 8-pin JST-SH 4-in-1 ESC interface, an LMR50410 buck plus a 3.3 V LDO regulating from 4S, native USB, and an SWD debug header. A later **v3** revision was started but never finished; it was removed (2026-09-03) because carrying an incomplete second project alongside the fabricated one is a source of confusion, not value. v2 is the revision that goes to fabrication.

This ADR records the concrete build commitment that 0026 left open: which board, which vendor, how many, at what cost, and what the second assembled board can and cannot become.

## Decision

### 1. Fabricate the v2 board, not v3

The revision sent to fabrication is `drone_fc` **v2** ([hardware/electrical/v2/](../../hardware/electrical/v2/)). v3 was an unfinished exploration and has been deleted. There is no partial second project to reconcile against; v2 is the single source of truth for this build.

### 2. Vendor: PCBWay turnkey PCBA (supersedes ADR 0026's Aisler selection)

The board is fabricated and assembled by **PCBWay** as a turnkey PCBA. This **supersedes [ADR 0026](0026-phase4-custom-pcba-nrf5340.md) §Consequences, which named Aisler** (2026-08-31).

The deciding factor is the same one 0026 weighed — external sourcing of the RF module — resolved the other way in practice: PCBWay quoted the full turnkey build *including* sourcing and placing the Raytac module, which removes the consign-the-module logistics that drove the original Aisler preference. The turnkey rationale from [ADR 0026 §9](0026-phase4-custom-pcba-nrf5340.md) is unchanged: a reflow house places the QFN/LGA IMU and the module reliably, keeping hand-solder joints out of bring-up.

### 3. Quantities: 5 fabricated, 2 assembled, 8 modules

- **5 bare boards** — PCBWay's minimum fabrication quantity.
- **2 assembled** — one flight unit and one spare. The spare has standalone value given the crash rate this project expects; a populated flight controller in a drawer is cheap insurance against a shattered board (compare [ADR 0019](0019-airframe-class-3in-4s-printed.md) / the PLA-shatter experience).
- **8 Raytac modules** — the module's minimum order quantity.

This leaves 3 spare bare boards and 6 spare modules. The spare boards enable a later hand or turnkey second-batch build; the spare modules are stock for future revisions. The MOQ overhang is accepted, not engineered around — it is cheaper to hold the surplus than to chase a smaller order.

### 4. Cost

_Figures to be filled from the final PCBWay quote and module order._

| Line item | Qty | Unit | Total |
| --- | ---: | ---: | ---: |
| PCB fabrication (5 boards) | 5 | £TBD | £TBD |
| Turnkey assembly (2 boards) | 2 | £TBD | £TBD |
| Raytac MDBT53 modules | 8 | £TBD | £TBD |
| Shipping / import | — | — | £TBD |
| | | **Total** | **£TBD** |

Cost is recorded here rather than left implicit so the learning-project spend is honest and future revisions have a baseline to compare against.

### 5. The spare can become a remote only via an external ADC

The second assembled board is primarily a spare flight controller. It can *also* serve as the radio remote ([ADR 0002](0002-mcu-and-language.md) currently assigns that role to the second micro:bit), because it is an identical nRF5340 — same antenna, same 802.15.4 PHY — which is the ideal both ends of the link. But not by wiring joysticks directly:

- The four ESC/DShot pins on v2 are **P0.03, P0.16, P0.17, P0.22** (M1–M4). **None are SAADC-capable.**
- The nRF5340's analog inputs are the fixed set AIN0–AIN7 (P0.04–P0.07, P0.25–P0.28). Of these, only four are broken out on v2, and all four are already used — P0.04 (current sense) and P0.27 (VBAT sense) as analog, P0.07 (SPI SCK) and P0.28 (status LED) as digital.

So there is **no path to four analog stick axes on this board**, and adding one needs a respin. The route that needs no respin: the ESC connector exposes five usable digital GPIO (the four motor pins plus P0.08), enough to hang an **external I²C/SPI ADC** (e.g. ADS1115 / MCP3008) that reads the potentiometers, with spare GPIO for arm/mode buttons. The remote is therefore a "spare board plus a small external-ADC harness on the ESC connector," not a direct-wire conversion.

## Fabrication file preparation (implementation notes)

Getting the board to a fabricable state needed two pieces of tooling beyond the KiCad project itself, kept under [hardware/electrical/tools/](../../hardware/electrical/tools/).

### Module footprint: converted from Raytac's Eagle library (vendor-neutral)

The Raytac MDBT53 is not in any stock KiCad library, so its footprint was generated from Raytac's manufacturer-supplied **Eagle** package by [convert_mdbt53_eagle.py](../../hardware/electrical/tools/convert_mdbt53_eagle.py). Three things had to be handled and are worth recording, because they bite silently:

- **Y-axis flip.** Eagle measures Y upward, KiCad downward. Copying pad/graphic coordinates verbatim mirrors the part — a left-right-flipped module that passes visual inspection but fails at assembly. The script negates every Y.
- **Pad-count assertion.** The converter asserts exactly 65 pads before writing anything, so a partial or wrong XML parse fails loudly instead of producing a plausible-looking short footprint.
- **Courtyard / antenna keepout drawn by hand.** Eagle's layer 41 carries RF keepout notes rather than a courtyard outline, so the courtyard rectangle and the "ANTENNA AREA" keepout are added explicitly rather than copied.

This work is independent of the fab house and stands whatever vendor is chosen.

### CPL / BOM reformatting: these outputs are JLCPCB-format

KiCad's native exports do not match a fab assembly template directly, so two scripts reshape them:

- [convert_cpl_for_jlcpcb.py](../../hardware/electrical/tools/convert_cpl_for_jlcpcb.py) turns KiCad's `Ref,Val,Package,PosX,PosY,Rot,Side` placement export into JLCPCB's `Designator,Mid X,Mid Y,Layer,Rotation` — renaming columns, normalising rotation to `% 360`, and capitalising the layer name.
- [make_minimal_bom.py](../../hardware/electrical/tools/make_minimal_bom.py) reduces the KiCad BOM to JLCPCB's `Comment,Designator,Footprint`, stripping the footprint-library prefix.

The committed [drone_fc-cpl-jlcpcb.csv](../../hardware/electrical/v2/) and [drone_fc-bom-minimal.csv](../../hardware/electrical/v2/) are therefore **JLCPCB-format**, produced while JLCPCB was still a candidate vendor. They do **not** transfer directly to a PCBWay turnkey order:

- PCBWay turnkey sources parts against **manufacturer part numbers**. The JLCPCB-minimal BOM carries none — but the full KiCad export [drone_fc-bom.csv](../../hardware/electrical/v2/) (`Refs,Value,Footprint,MPN,Qty,DNP`) does, so a PCBWay BOM should be built from that, not the minimal one.
- Gerbers for PCBWay were exported separately ([drone_fc-pcbway-gerbers.zip](../../hardware/electrical/v2/)); the placement/BOM files still need regenerating to PCBWay's expected format before the order.

## Consequences

- **Commits real spend and lead time** on 5 boards, 2 assemblies, and 8 modules — sequenced in parallel with continued micro:bit tuning, per [ADR 0026](0026-phase4-custom-pcba-nrf5340.md), not blocking it.
- **Supersedes the Aisler choice** in [ADR 0026](0026-phase4-custom-pcba-nrf5340.md); that line is marked superseded there.
- **v3 is gone** — one board revision in the tree, no ambiguity about what was built.
- **MOQ overhang:** 3 spare bare boards and 6 spare modules on the shelf. Not waste — stock for the next revision or a hand-built second batch.
- **A flight-ready spare** exists from day one, and a remote is reachable from it without a respin via an external ADC (§5).
- **Establishes the fabrication baseline** — vendor, quantities, and cost for this board are on record for future revisions to compare against.

## Open questions

- Final cost figures (§4) — pending the PCBWay quote and module order.
- Lead time and the module consign-vs-vendor-source logistics with PCBWay.
- **Regenerate the placement and BOM files in PCBWay's required format** before ordering — the committed CPL/BOM are JLCPCB-format, and a PCBWay turnkey BOM must be built from the MPN-bearing [drone_fc-bom.csv](../../hardware/electrical/v2/), not the minimal JLCPCB BOM (see fabrication file notes).
- **Pre-fab verification of the reversed 8-pin JST-SH ESC pinout** — the v2 symbol numbers pin 1 as the motor end, not the power end ([hardware/electrical/parts-list.md](../../hardware/electrical/parts-list.md)). Getting VBAT (pin 8, up to 16.8 V) onto an MCU GPIO is destructive, not merely confusing. Continuity check from the ESC battery pad through the harness before the order is placed.
- Board bring-up order and a power-on checklist — its own doc once boards arrive.

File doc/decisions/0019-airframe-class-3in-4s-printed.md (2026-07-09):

# ADR 0019 — Airframe and propulsion class: 3" ducted, 4S, fully 3D-printed frame

- **Status:** Proposed
- **Date:** 2026-06-14
- **Related:** [ADR 0001](0001-platform-airframe-stack.md) (quadcopter, real hardware, learning-first), [ADR 0006](0006-mechanical-cad-fusion360.md) (Fusion 360 for mechanical CAD), [00-vision.md](../00-vision.md) "Definition of success" (Phase 3 commits flight hardware)

## Amendments

- **2026-06-28 — motors ordered are 1404, not 1507-class.** The first propulsion order
  ([hardware/electrical/parts-list.md](../../hardware/electrical/parts-list.md)) selects iFlight
  XING2 **1404** 3800 KV motors, a smaller stator than the **1507-class** named in the Decision
  below. Accepted without superseding this ADR: the KV (3800) is within the stated band, the lighter
  motor only improves the AUW headroom this ADR sets (~280 g / T:W 1.8 ceiling), and thrust at
  3"/4S/1404/3800 KV stays comfortably above the ~2:1 T:W target for the ~200 g build. The 1507-class
  figure remains the nominal reference; treat 1404 as the as-built value. If the actual AUW or thrust
  measurements fall short of the ADR's budget, that triggers a superseding ADR, not a stretch of this
  one. The ESC ordered (Sequre Blueson A1, 65 A) likewise exceeds the 25–35 A class figure — harmless
  headroom, not a deviation, since that figure was a minimum.

## Context

[ADR 0001](0001-platform-airframe-stack.md) committed to a real-hardware quadcopter with rolled-from-scratch firmware, but explicitly left frame class, motors, ESCs, battery, and radio link open. The Phase 3 milestone in [00-vision.md](../00-vision.md) requires those choices to be *committed* before flight hardware is bought, because every part downstream of the frame depends on the prop class and cell count.

Phase 1 firmware bring-up is in progress on bench hardware (micro:bit v2 + ICM-42688 + bench PSU, no airframe). Bench testing remains workable for several more weeks without an airframe. But three things make this the right time to lock the class in:

- **Motor / ESC product cycles take weeks.** Specific parts go out of stock; deciding the *class* now lets the eventual order happen on a known catalogue.
- **The frame is going to be designed in-house and 3D-printed**, not bought. The frame design depends on motor mounting hole pattern and AUW estimate, both of which are pinned by the class.
- **The bench enclosure** required by Phase 2 ([07-safety.md A.8](../07-safety.md), referenced from 00-vision) needs to be sized for the airframe. Building the enclosure ahead of the first props-on full-power run only works if the airframe size is known.

The relevant axes are:

1. **Prop class** (2.5" / 3" / 3.5" / 4" / 5" / 7"). Drives motor stator size, ESC current rating, battery capacity, frame size, noise, safety profile, and how badly a crash hurts.
2. **Battery cell count** (3S / 4S / 6S). Drives motor KV, ESC voltage rating, and ecosystem breadth.
3. **Frame construction** (carbon-fibre kit / hybrid / fully printed). Drives stiffness, weight, crash cost, and how much of the build the author owns.
4. **Frame style** (naked X / ducted / cinewhoop). Drives safety, noise, and structural stiffness of the printed frame.

All four are coupled — it's one decision, not four.

## Decision

The first flight airframe is:

- **Prop class: 3"** (three-inch propellers, tri-blade).
- **Battery: 4S LiPo** (~14.8 V nominal, capacity 450–650 mAh, XT30 connector).
- **Motors: 1507-class brushless**, ~3500–3800 KV (specific part number deferred to ordering time).
- **ESC: 4-in-1 stack ESC**, 25–35 A continuous on 4S, DShot300/600 capable, 20×20 mm or 25.5×25.5 mm mounting standard (specific part number deferred).
- **Frame style: ducted** (cinewhoop-style), four ducts on a centre plate.
- **Frame construction: fully 3D-printed**, in PETG (PLA acceptable for prototypes; PETG for the build that flies). Modular: separate base / duct / canopy parts, each independently replaceable after a crash.

Estimated all-up weight: ~200 g with battery and electronics. Estimated thrust budget: ~500 g at full throttle (4× motors). Thrust-to-weight ratio: ~2.5:1 — comfortable margin.

This is the **class** decision only. The specific frame `.f3d` lives under `hardware/mechanical/` and evolves freely without re-opening this ADR. The specific motor / ESC / battery part numbers are recorded at ordering time as a `hardware/electrical/parts-list.md` (or similar) — also not in scope of this ADR.

## Why this shape

### Why 3" specifically

- **Garden-flyable.** A 3" cinewhoop with ducts is honest-to-god safe to fly in a small back-garden environment. 5" is not. 4" is borderline. 2.5" is safe but payload-constrained.
- **Thrust budget survives a heavy build.** The author's first flight controller is a micro:bit-strapped-to-the-frame stack with hand-wired peripherals. That's substantially heavier than a purpose-built FC. At 3" / 4S / 1507, the thrust budget absorbs the extra weight without making the quad sluggish (T:W ≈ 2.5:1 even on the high end of the AUW estimate).
- **Crash damage is bounded.** A 3" prop in PLA / PETG arms in a duct does not break much when it hits the ground. The author *will* crash it many times during PID tuning and firmware bring-up; cheap-to-replace airframe is essential.
- **Largest deep-resource pool for the size.** "3" cinewhoop" is the most popular printed-frame class on Printables / Thingiverse / FPV community forums. Reference designs, motor recommendations, and tuning notes are abundant.

2.5" was rejected as too constrained on payload — borderline T:W with this build's electronics weight, and not enough headroom for a future Phase 6+ analog FPV camera ([00-vision.md](../00-vision.md) "Beyond Phase 5"). 4" was rejected as the point where printed arms genuinely start to flex enough to interact with the IMU during flight; carbon-fibre arms become the right answer at that size, which conflicts with the "made it myself" frame goal below. 5"+ is out of garden-flying scope.

### Why 4S

- **Universal default for the size.** Tutorials, motor catalogues, and ESC product pages at 1507-class assume 4S unless otherwise stated.
- **Cheaper batteries than 6S** at the relevant capacity. 4S 450–650 mAh packs are £8–12 each.
- **Lower current at the same power than 3S.** At 3S the motors would need higher KV and the ESCs would see ~33% more current, pushing into uncomfortably hot territory for a printed-frame build with limited airflow.
- **6S is overkill at 3"** and the available 1507-class motor KVs assume 4S.

### Why ducted

A duct is a circular shroud (a ring) around each propeller, integrated into the frame structure. The arguments for it specifically *given* a 3D-printed frame:

- **Structural stiffening.** The duct is a closed ring — it resists out-of-plane bending much better than a printed open arm of the same mass. The duct *helps* the printed-frame stiffness problem rather than fighting it.
- **Finger / wall / face protection.** The duct stops anything from touching the prop tips. The author lives with people; the drone will be flown indoors during bench tests; this is non-negotiable.
- **Quieter.** Duct flow reshapes the prop tip vortex; cinewhoops sound like vacuums, not chainsaws. Garden flying with neighbours benefits.
- **Bumper for free.** A duct is also a crash bumper. Hitting a wall doesn't immediately mean broken props.
- **Slight thrust efficiency improvement at hover.** Net positive, even on a short printed duct, but not the main reason to choose this.

The cost is mass (a ducted printed frame is ~2× the mass of a naked printed frame of the same span) and forward-flight drag. Neither matters for this build's mission profile (hover, tune, bench-test, garden) and the thrust budget at 3"/4S/1507 absorbs the mass.

### Why fully printed (not hybrid CF + printed)

The author can already 3D print, has Fusion 360 ([ADR 0006](0006-mechanical-cad-fusion360.md)), and has explicitly stated that **"made every part of it"** is a goal. The drone is the vehicle for learning ([ADR 0001](0001-platform-airframe-stack.md)). Buying a CF arm kit reduces the build's surface area for learning by removing the entire mechanical-design layer. That's the wrong trade for this project.

The classic objection to fully-printed frames is **stiffness at 5"+ with naked arms**. That objection does not apply at 3" with ducted arms (see "Why ducted" above) — the duct ring, not the arm material, dominates the stiffness budget at this size.

The remaining cost is iteration time when the frame breaks: ~1–2 hours of print time per arm vs. instantly-replaceable CF parts. That cost is acceptable. It is also a learning-positive cost — every reprint is a chance to refine the design.

## Consequences

### What this commits us to

- **A bench enclosure sized for a ~25–30 cm-span 3" cinewhoop** with battery and electronics (Phase 2 prerequisite per [00-vision.md](../00-vision.md) and `07-safety.md`).
- **A frame design in Fusion 360** under `hardware/mechanical/`, parameterised around a 1507-class motor mounting hole pattern (verified against the specific motor at order time) and a 3" prop diameter with ~1 mm tip-to-duct clearance. Frame revisions evolve under that design without re-opening this ADR.
- **Modular frame structure** — base / four ducts / canopy as separate printed parts bolted together — so a single broken duct does not require reprinting the whole airframe.
- **PETG as the production filament** for the airframe that flies. PLA prints first iterations during geometry development; PETG is what the prototype crashes in.
- **Future ESC and motor orders** are constrained to **DShot-capable, 4S-rated, ~25–35 A** ESCs and **1507-class, ~3500–3800 KV** motors. Specific parts (T-Motor / EMAX / iFlight / BetaFPV / etc.) chosen at order time on the catalogue then current.
- **Battery and charger commitments**: 4S LiPo 450–650 mAh, XT30 connector. A proper LiPo balance charger is a Phase 2 prerequisite — flying without one is a fire risk regardless of frame class. Charger purchase is **not** gated by this ADR; it can land any time.
- **Thrust-to-weight planning headroom**: the design AUW budget is ~200 g; if the actual build comes in over ~280 g (T:W < 1.8) the class is no longer adequate and this ADR gets superseded rather than stretched.

### What this rules out

- **No carbon-fibre arms or plates** in the first-arc airframe. This includes hybrid CF/printed builds. Re-opens only as a superseding ADR if printed-frame dynamics turn out to be a blocker.
- **No 5" / 6S / freestyle build** in the first arc. That is a separate, future quad if the author chooses to build one.
- **No naked X (un-ducted) frame** for the first build. Safety and printed-frame stiffness both push toward ducted.
- **No payload assumptions beyond the planned electronics + battery + a future small analog FPV camera + VTX (~20–30 g extra).** Larger payloads (HD camera, GPS module, additional batteries) are not on the table for this airframe class. Phase 6+ analog FPV remains a planned use ([00-vision.md](../00-vision.md) "Beyond Phase 5") and fits the budget.
- **No motor / ESC / battery purchases before the frame's first physical print and a fit-check.** Ordering motors before mounting holes are validated is how spare-parts boxes happen.

### What stays open

- **Specific motor part number.** 1507-class @ ~3500–3800 KV is the spec; the actual brand and model gets picked at order time and recorded as part of `hardware/electrical/parts-list.md`. Re-decision is not an ADR; it's a parts-list update.
- **Specific ESC part number.** 4-in-1, DShot-capable, 4S, ~25–35 A is the spec; same treatment as motors.
- **Battery capacity within the 450–650 mAh band.** Trade-off is hover time vs. mass; resolved empirically once the frame's actual AUW is known.
- **Radio link.** Still deferred ([AGENTS.md](../../AGENTS.md) "Next open questions"). Second micro:bit is the Phase 1–2 placeholder. The radio choice does not block this ADR.
- **Frame geometry.** Span, duct height, motor pitch, mounting points for the FC stack, battery strap routing — all decided in the Fusion 360 design under `hardware/mechanical/`. This ADR pins the *class* the geometry must satisfy, not the geometry itself.
- **Bench rig vs. flight frame.** It may be useful to print a deliberately-stiff "bench rig" (one motor, one prop, isolated from the flight frame) for early firmware bring-up, separate from the flight airframe. That's a [hardware/](../../hardware/README.md) decision, not an ADR.
- **Phase-4 PCBA mounting in this frame.** The custom nRF5340 PCBA from [00-vision.md](../00-vision.md) Phase 4 is intended to *replace* the micro:bit on this frame. The frame design should leave room for that swap, but the PCBA's outline is its own future ADR.

## References

- [00-vision.md](../00-vision.md) — Phase 3 commits flight hardware; 3" / 4S meets that bar.
- [ADR 0001](0001-platform-airframe-stack.md) — quadcopter, real hardware, learning-first scope (parent).
- [ADR 0006](0006-mechanical-cad-fusion360.md) — frame `.f3d` + `.stl` lives in Fusion 360.
- [Printables — 3" cinewhoop frames](https://www.printables.com/search/models?q=3%20inch%20cinewhoop) — reference designs to study before designing one.
- [Oscar Liang's drone build guides](https://oscarliang.com/) — community reference for motor / ESC / battery pairings at common classes.
- BetaFPV / T-Motor / EMAX / iFlight — vendors with reliable spec sheets at the 1507 / 4S / 3" class.
- Implementation: `hardware/mechanical/` (frame design — to be created), `hardware/electrical/parts-list.md` (motor / ESC / battery selections at order time — to be created), bench enclosure (Phase 2 prerequisite — to be designed).

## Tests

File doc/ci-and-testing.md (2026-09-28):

# CI and testing

How the project keeps `main` green. Tracks the strategy in [ADR 0007](decisions/0007-testing-and-ci-strategy.md); this file is the practical "how to run it" companion.

## What is tested where

Host-testable logic lives in crates with no HAL / async-runtime / `defmt` dependency, so `cargo test` runs them on the developer's workstation with no cross toolchain:

- `firmware-types` — wire types, newtype invariants (`Throttle` clamping / NaN-scrub), postcard round-trips.
- `firmware-drone-core` — the supervisor failsafe state machine.
- `firmware-remote-core` — remote-side pure logic (input mapping, parsing) as it lands.
- `groundstation` — host-only egui app; pure helpers (state mapping, framing) as they are extracted out of `main.rs`.

On-target firmware crates (`firmware-drone-microbit`, `firmware-drone-shared`, `firmware-remote`) need a cross target and per-crate linker flags, so they are **not** part of `cargo test`. Their logic is meant to live in the matching `-core` crate. Hardware-in-the-loop testing is deferred (ADR 0007).

## Running the tests

Tests are run with [cargo-nextest](https://nexte.st/), which gives a single aggregated summary (`Summary [..] N tests run: N passed`) instead of one block per test binary. Install it once:

```sh
cargo install cargo-nextest --locked
```

From the repo root:

```sh
cargo nextest run                                              # workspace default-members
cargo nextest run --manifest-path crates/groundstation/Cargo.toml   # host-only, excluded from the workspace
```

The root run honours `default-members` in the top-level `Cargo.toml`, which lists exactly the host-testable workspace crates (per ADR 0015). `groundstation` is intentionally excluded from the workspace, so it needs its own invocation.

Plain `cargo test` still works and is the fallback if nextest is not installed; it just prints per-binary results and does not aggregate. Note nextest does not run doctests (there are none currently); if any are added, run `cargo test --doc` alongside.

## Pre-push hook

A tracked `pre-push` hook runs both test scopes before any push is allowed, so a green `main` does not depend on remembering to run `cargo test`.

The hook lives at [`.githooks/pre-push`](../.githooks/pre-push) (tracked in the repo, unlike `.git/hooks/`). Git does not use a tracked hooks directory automatically — **enable it once per clone**:

```sh
git config core.hooksPath .githooks
```

To bypass in a genuine emergency: `git push --no-verify` (discouraged; the next push runs the tests anyway).

The hook runs `cargo nextest run` only (and fails with an install hint if nextest is missing). Format and lint enforcement (`cargo fmt --check`, `cargo clippy`) per [ADR 0012](decisions/0012-lint-and-format-policy.md) runs in CI rather than the hook, to keep the local push fast.

## GitHub Actions

[`.github/workflows/ci.yml`](../.github/workflows/ci.yml) runs on every push to `main` and on every pull request. It is the server-side backstop the local hook cannot guarantee (a contributor may not have enabled the hook, or may have used `--no-verify`).

Two `ubuntu-latest` jobs run in parallel, each doing `cargo fmt --check`, `cargo clippy --all-targets -- -D warnings` ([ADR 0012](decisions/0012-lint-and-format-policy.md)) and `cargo nextest run`:

1. **host-checks** — the workspace host crates (`default-members`: `firmware-types` + the `*-core` crates). No system dependencies.
2. **groundstation** — the out-of-workspace GUI crate. It first installs the Linux libraries `eframe`, `gilrs` and `serialport` link against (`libudev-dev`, `libxkbcommon-dev`, `libwayland-dev`, the X11/GL dev libs); these are needed only to compile and link — the tests open no window, so no headless display is required.

On-target firmware crates need a cross target and hardware, so they are not built in CI (HIL deferred, ADR 0007). Rust is the stable toolchain; nextest is installed via [`taiki-e/install-action`](https://github.com/taiki-e/install-action) and the cargo build is cached with [`Swatinem/rust-cache`](https://github.com/Swatinem/rust-cache).

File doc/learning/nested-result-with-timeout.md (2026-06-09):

# Nested `Result` from `with_timeout`

_Captured 2026-05-30 while writing `receive()` in `firmware-remote/src/tasks/drone_link.rs` (then named `comm_link.rs`). Easily the most confusing Rust syntax encountered so far._

## The question

`embassy_time::with_timeout(duration, future)` wraps any future with a timeout. Its signature is roughly:

```rust
pub async fn with_timeout<F: Future>(duration: Duration, fut: F)
    -> Result<F::Output, TimeoutError>;
```

If you call it on a future that *itself* returns a `Result`, you get a `Result<Result<T, E>, TimeoutError>` — a `Result` inside a `Result`. Three things can have happened:

1. The future finished successfully.
2. The future finished with an error.
3. The timeout fired (the future never finished).

The Rust syntax for distinguishing all three reads alien at first. This note collects the patterns I tried, what they look like, and which one is idiomatic.

## The concrete case

```rust
match with_timeout(
    Duration::from_millis(100),
    radio.receive(&mut rx_packet),
).await {
    Ok(Ok(())) => { /* got a packet */ }
    Ok(Err(e)) => { /* radio error */ }
    Err(_)     => { /* timeout */ }
}
```

- Outer `Result` is from `with_timeout`: `Ok(inner_result)` if the future completed, `Err(TimeoutError)` if it didn't.
- Inner `Result` is from `radio.receive`: `Ok(())` on success, `Err(RadioError)` on failure.

The patterns `Ok(Ok(()))` and `Ok(Err(e))` look like nested function calls but they aren't — they're patterns describing the *shape* of the value. They read "outer is `Ok`, and the thing inside is `Ok(())`" or "outer is `Ok`, and the thing inside is `Err(e)`."

This is the same idea as destructuring a struct in a function argument: you're not building anything, you're matching a layout that already exists.

## Three styles, all equivalent

### Style 1: one flat match (recommended)

```rust
match with_timeout(Duration::from_millis(100), radio.receive(&mut rx_packet)).await {
    Ok(Ok(()))  => {}                                                       // success — fall through
    Ok(Err(e))  => { defmt::warn!("radio error: {:?}", e); return None; }
    Err(_)      => { defmt::warn!("timeout");              return None; }
}
```

Three arms, three outcomes, one match. This is the version a Rust reviewer would write. The nested `Ok(Ok(()))` pattern is the bit that looks weird but it's purely descriptive — read it as "outcome is Ok, and inside is Ok of unit."

### Style 2: peel one layer at a time

```rust
let outcome = with_timeout(Duration::from_millis(100), radio.receive(&mut rx_packet)).await;

let rx_result = match outcome {
    Ok(r) => r,                                                             // unwrap outer
    Err(_) => { defmt::warn!("timeout"); return None; }
};

if let Err(e) = rx_result {                                                 // check inner
    defmt::warn!("radio error: {:?}", e);
    return None;
}
```

More lines, but each step is one decision: "did the timeout fire? OK, now did the radio succeed?" Useful as a teaching aid; verbose for production. The intermediate `rx_result` is the only thing carrying meaning — without a name for the peeled value, you'd be back to the nested pattern from Style 1.

### Style 3: `.ok()??` chain (terse, loses logging)

```rust
with_timeout(Duration::from_millis(100), radio.receive(&mut rx_packet))
    .await
    .ok()?      // Result<_, TimeoutError> → Option, ? returns None on timeout
    .ok()?;     // Result<(), RadioError>  → Option, ? returns None on radio error
```

Four lines, no match at all. The trick:

- `.ok()` on a `Result<T, E>` discards the error and gives `Option<T>`.
- `?` on an `Option` inside a function returning `Option<_>` unwraps `Some` or returns `None`.

Together, `.ok()?` reads as "if this succeeded, give me the value; otherwise bail out of the function with `None`." Apply twice to peel both layers.

The cost: you can't tell whether the function returned `None` because of a timeout or because of a radio error. For initial bring-up that's fine. Once you have a failsafe (drone disarms after N missed commands), you'll want to distinguish them — at which point Style 1 returns.

## What I tried that did not work

### Mistake 1: empty `Ok` arm

```rust
let rx_result = match outcome {
    Ok(r) => {},                  // <-- returns () instead of r
    Err(_) => return None,
};
```

The `{}` block evaluates to unit `()`, so `rx_result: ()`. The next `if let Err(e) = rx_result` then fails to compile because you can't pattern-match `Err(e)` against `()`. Fix: `Ok(r) => r,` (no braces — or `Ok(r) => { r }` with the value as the last expression).

This is the single most common Rust beginner mistake when coming from C/JS: forgetting that **blocks are expressions** and an empty block has value `()`, not "no value."

### Mistake 2: mixing styles half-and-half

After peeling the outer layer into `rx_result: Result<(), RadioError>`, then trying to match it with arms from Style 1:

```rust
match rx_result {
    Ok(Ok(())) => {}             // <-- won't compile
    Ok(Err(e)) => { ... }        // <-- won't compile
    Err(_)     => { ... }
}
```

`rx_result` only has one layer of `Result` left, so patterns like `Ok(Ok(()))` don't match its type. The compiler error is clear once you see it, but easy to produce while refactoring between styles. Pick one and commit to it.

## Why this is awkward in Rust specifically

In C you'd write:

```c
if (timed_out) { ... return; }
int rc = radio_receive(&pkt);
if (rc != 0)   { ... return; }
// use pkt
```

Two flat checks, each on a single value. The error path and the timeout path are separate concepts at the source level.

Rust folds both into the type system: a `Result` is the value-or-error, and `with_timeout` adds another `Result` layer for the timeout-vs-completed distinction. This is more honest (everything is in the type) and forces you to handle every case (the compiler will refuse a non-exhaustive match), but it produces these nested types that look noisy at first.

The cure is to recognise the pattern. Once you've seen `Result<Result<T, E1>, E2>` a few times — and it shows up *everywhere* `with_timeout` is used — the three-arm match becomes muscle memory.

## The general lesson

When a future-returning combinator wraps another future-returning thing that has its own error, you get nested `Result`s. Don't fight it. Pattern-match it flat:

| Outer | Inner | Meaning |
|---|---|---|
| `Ok`  | `Ok(v)` | Both succeeded |
| `Ok`  | `Err(e)`| Inner future failed |
| `Err` | _n/a_ | Outer combinator failed (timeout)|

For two-layer cases, one flat match is the right answer. For deeper nesting (rare), peel layer-by-layer with named intermediates so each decision is readable.

## Related Embassy combinators that produce nested results

- `with_timeout(d, fut)` → `Result<Output, TimeoutError>`.
- `select(a, b)` / `select3` / `select4` → `Either<A::Output, B::Output>` (not a `Result` but the same shape-matching applies).
- `join(a, b)` → `(A::Output, B::Output)` — a tuple. If both are `Result`s, you have `(Result, Result)` to inspect.

Same playbook for all of them: write out the three (or four) arms explicitly, let the compiler check exhaustiveness, ship.

## Sources

- Embassy `with_timeout`: <https://docs.embassy.dev/embassy-time/git/default/fn.with_timeout.html>
- Rust book, "Patterns and Matching": <https://doc.rust-lang.org/book/ch18-00-patterns.html>
- Rust by Example, "Combinators: and_then, etc.": <https://doc.rust-lang.org/rust-by-example/error/option_unwrap/and_then.html> (alternative style: chain combinators instead of matching)

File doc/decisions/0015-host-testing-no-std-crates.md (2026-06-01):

# ADR 0015 — Host-testable `no_std` crates: wiring pattern

- **Status:** Accepted
- **Date:** 2026-06-01
- **Related:** [ADR 0007](0007-testing-and-ci-strategy.md) (strategy), [ADR 0009](0009-workspace-bootstrap-and-crate-naming.md) (crate split), [ADR 0012](0012-lint-and-format-policy.md)

## Context

[ADR 0007](0007-testing-and-ci-strategy.md) committed us to unit-testing all non-trivial logic on the host, and made the `core` / `task` split a hard rule precisely so this is possible. It deliberately left tooling and concrete wiring open.

The first real test suite (`crates/firmware-types`, postcard round-trip and `Throttle` invariant tests) forced those open questions to be answered. The crate is `no_std` on the target but needs `std` in `cargo test`. Several papercuts surfaced:

1. **`#![no_std]` blocks `cargo test`.** The default test harness needs `std` (the `test` crate links it). A crate marked `#![no_std]` unconditionally won't build for tests on the host.
2. **Workspace-shared `postcard` pulls in `use-defmt`.** Our `[workspace.dependencies] postcard` enables `use-defmt` for the on-target use. As a `[dev-dependencies]` reused via `workspace = true`, the feature came along too, and the test binary failed to link with unresolved `_defmt_*` externals because no global logger is registered on the host.
3. **`cargo test` from the workspace root tries to test firmware crates.** `firmware-drone` / `firmware-remote` are `no_std` Cortex-M binaries with custom panic handlers. Compiling their test harness for the host fails with `can't find crate for test` and `#[panic_handler] function required`.
4. **VS Code Testing view's "Run All" invokes `cargo test --workspace`,** which trips problem 3. Per-test CodeLens arrows work because they pass `-p <crate>`.

None of these are decisions in the ADR-0007 sense — they're implementation details. But the right shape is non-obvious if you've not hit it before, and getting it wrong wastes a session. Worth recording the pattern once.

## Decision

### 1. Host-testable `no_std` crates use conditional `no_std`

For any crate that compiles `no_std` on target but needs `std` for its test harness:

```rust
#![cfg_attr(not(test), no_std)]
```

Effect: `no_std` for normal builds (target and host alike), `std` for `cargo test`. The crate's own code must stay `no_std`-compatible — `cargo build` from the repo root will still fail any `std`-only API use.

This applies to `firmware-types`, `firmware-drone-core`, `firmware-remote-core`, and any future `*-core` / shared crate.

It does **not** apply to firmware bin crates (`firmware-drone`, `firmware-remote`). Those stay `#![no_std]` unconditionally — they have no host tests and live behind the `default-members` filter (see point 4).

### 2. Tests live as inline `#[cfg(test)] mod tests`

Per-file `mod tests` blocks at the bottom of the source file, **not** a top-level `tests/` directory. Reasons:

- Inline tests can exercise private items via `use super::*;`. The wire-format invariant tests on `Throttle` need that — the inner `f32` is private.
- `tests/` integration tests compile as separate crates and can only see the public API. Use them only when the test deliberately wants to assert "this works the way a downstream consumer would use it".
- Inline tests are conventional in idiomatic Rust crates (per AGENTS.md "prefer the idiomatic choice").

### 3. `[dev-dependencies]` are pinned **directly**, not via `workspace = true`

When a host test needs a crate that the same project uses on target with different features, declare it under `[dev-dependencies]` with its own explicit version and feature set:

```toml
[dev-dependencies]
# Pinned directly (not via workspace) to avoid the workspace `use-defmt`
# feature, which would require a global defmt logger that doesn't exist
# on host.
postcard = { version = "1", default-features = false }
```

The version still matches the workspace pin (kept consistent by review, same as any duplicated literal). The comment is mandatory — it tells the next reader why the pattern was chosen over `workspace = true`.

This is the **only** sanctioned exception to ADR 0009's "use `workspace = true` for shared deps" rule. The cost (one duplicated version literal) buys us a clean host build without polluting target features.

### 4. Workspace tests run via `default-members`, never `--workspace`

`Cargo.toml` already lists host-buildable crates in `[workspace.default-members]`. `cargo test` from the repo root (no flags) honours that list and skips firmware bin crates. **This is the canonical command for running the full host test suite.**

- `cargo test --workspace` is **forbidden** in this project. It will try to build firmware bin crates for the host and fail.
- `cargo test -p <crate>` is the right thing for focused runs.
- CI invokes `cargo test` from the repo root, no `-p`, no `--workspace`.

### 5. VS Code Test Explorer is best-effort

rust-analyzer's Testing view ("beaker icon") is enabled (`"rust-analyzer.testExplorer": true`). It populates from discovered `#[test]` functions and lets you run individual tests or whole modules with their correct `-p <crate>` scope.

The **"Run All Tests"** button at the top of the Testing view invokes `cargo test --workspace` with no opt-out. **Do not use it.** Use one of:

- **CodeLens ▶ Run Test** arrows above each `#[test]` (per-test, correctly scoped). Primary workflow.
- **CodeLens ▶ Run Tests** above each `mod tests` (per-module).
- **Terminal:** `cargo test` from the repo root for the full suite (honours `default-members`).

A VS Code task bound to a hotkey is a reasonable upgrade if the terminal hop becomes annoying; not done preemptively.

## Why this shape

- **`cfg_attr(not(test), no_std)`** is the standard pattern in the embedded Rust ecosystem (used in `heapless`, `embedded-hal`, `serde-core` and many others). It costs one line and a one-time conceptual step; the alternative ("two crates, one `no_std`, one `std`-using wrapper for tests") is far heavier for the same outcome.
- **Inline `mod tests`** is what `cargo new --lib` generates and what 90% of the ecosystem uses. Privacy access is the killer feature; we use it on the `Throttle` invariant tests.
- **Pinned dev-dependencies for feature divergence** is uglier than `workspace = true`, but the alternative is either (a) splitting our `postcard` workspace dep in two (`postcard-target` / `postcard-host`) which is worse, or (b) silently broken host builds. Pin + comment wins.
- **`default-members` over `--workspace`** is a feature explicitly designed for mixed embedded/host workspaces. Using it is the idiomatic answer, not a workaround.
- **Accepting "Run All Tests" is broken in VS Code** is the honest position. rust-analyzer has no setting to scope it; chasing a workaround (e.g. `rust-analyzer.runnables.extraArgs = ["-p", "firmware-types"]`) would scope **every** runnable to one crate, breaking per-test runs in any future testable crate. Better to teach the (single) developer to use the working buttons.

## Consequences

### What this commits us to

- Every host-testable `no_std` crate uses `#![cfg_attr(not(test), no_std)]`.
- Tests live inline in `#[cfg(test)] mod tests`. `tests/` only for deliberate "integration test against public API".
- New `[dev-dependencies]` whose feature set differs from the on-target use are pinned directly with a comment explaining why.
- The canonical "run all host tests" command is `cargo test` (no flags) from the repo root.
- CI uses the same command.
- The pre-push hook (when it exists, per ADR 0007) will use the same command.

### What this rules out

- `#![no_std]` on host-testable crates (use `cfg_attr` instead).
- `cargo test --workspace` invocations anywhere — scripts, CI YAML, documentation, terminal aliases.
- Treating the Testing view's "Run All" button as a working primary workflow.
- Adding test-only test infrastructure to firmware bin crates without first splitting the testable logic into a `*-core` crate (which is already ADR 0007's hard rule).

### What stays open

- Whether to add a `[tasks]` or `xtask` entry that wraps `cargo test` + `cargo clippy` + `cargo fmt --check` as a single command. Deferred to when the pre-push hook lands (ADR 0007).
- Coverage tooling. Same parking-lot status as ADR 0007.
- HIL test wiring (`embedded-test`) — Tier 2 of ADR 0007, not in scope here.

## References

- ADR 0007 — testing strategy (the "what" and "why" this ADR realises).
- ADR 0009 — crate naming and the `workspace = true` rule that point 3 carves an exception to.
- Implementation: [`crates/firmware-types/`](../../crates/firmware-types/) — first crate to use this pattern end-to-end.
- [The Embedded Rust Book — `no_std` testing](https://docs.rust-embedded.org/book/intro/no-std.html) — background on the `cfg_attr(not(test), no_std)` idiom.

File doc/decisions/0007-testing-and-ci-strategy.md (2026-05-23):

# ADR 0007 — Testing and CI strategy

- **Status:** Accepted
- **Date:** 2026-05-23
- **Related:** [ADR 0001](0001-platform-airframe-stack.md), [ADR 0004](0004-concurrency-embassy-channels.md), [ADR 0005](0005-pc-software-language-rust.md), [02-architecture.md](../02-architecture.md)

## Context

The project is a roll-your-own flight controller built primarily for learning ([ADR 0001](0001-platform-airframe-stack.md)). The blast radius of "code that compiles, flashes, doesn't work, kills props" is real even on the bench, and gets worse at every phase boundary. We also commit often (AGENTS.md commit discipline) and want to keep `main` runnable on real hardware at all times.

Two things make testing genuinely tractable here:

1. **A lot of flight-controller logic is pure functions of numbers.** Mahony filter, PID, motor mixer, attitude math, quaternion ops, protocol serialization — none of it needs a HAL to be exercised. If we structure the code so this logic doesn't accidentally depend on the HAL, we can test it on the host with regular `cargo test`.
2. **Embedded Rust HIL (hardware-in-the-loop) tooling has matured.** `embedded-test` lets `#[test]` functions compile into a firmware binary, run on real hardware via `probe-rs`, and report results back to the host as if they were normal `cargo test` output. Self-hosted GitHub Actions runners with tethered boards make this a viable CI tier, not just a manual workflow.

The user's stated preferences: **unit test everything possible; quick local feedback before anything reaches CI.**

## Decision

### 1. Tests are first-class, not optional

- **All non-trivially-correct logic gets unit tests.** The bar is "can I write a host-runnable test for this?" not "do I have time for tests today?". If the answer is yes, the test exists.
- **Algorithmic / numeric code is mandatory to test.** Filters, controllers, mixers, attitude math, framing, serialization — no excuses.
- **Glue / HAL-wiring code is exempt** from unit tests (until HIL exists), but should be kept thin enough that it can't go wrong in interesting ways.

### 2. `core` / `task` split (architectural rule)

To make rule 1 possible, every firmware actor is structured as **two pieces**:

- **`core`** — a pure module of types and functions with no HAL dependency, no timers, no DMA, no Embassy. Takes inputs, returns outputs. Host-testable with `cargo test` on the workstation.
- **`task`** — the thin Embassy task wrapper that owns peripherals, reads from the inbox channel, calls `core`, and dispatches the results. Not unit-tested; covered by HIL later.

This is a hard rule, not a guideline: if a new actor can't be split this way, that is itself a design smell worth fixing.

### 3. Local-first feedback loop

- **CI and "what I run locally" are the same recipe.** A single task-runner script (likely `cargo xtask`; tool not formally locked here) defines the full check suite. Both the local git hook and the GitHub Actions workflow invoke it. No drift.
- **A `pre-push` git hook is committed to the repo** under `tools/git-hooks/`, with a one-shot installer script that the developer runs after cloning. The hook runs the same recipe. Push is blocked if it fails.
- **`--no-verify` is the conscious escape hatch.** The hook stays strict; bypass it deliberately when needed.

### 4. CI tiers, adopted in order

- **Tier 0 — Static checks (from day one of code):** `cargo fmt --check`, `cargo clippy -D warnings`, `cargo check`, `cargo doc --no-deps`, across all crates and targets. GitHub Actions on every push and PR.
- **Tier 1 — Host-side unit tests (as soon as testable code exists):** `cargo test` on the workspace, exercising every `core` module and the `proto` crate. Run locally first (rule 3) and in CI.
- **Tier 2 — Hardware-in-the-loop (desired end state, deferred):** `embedded-test` running on real micro:bit / nRF5340 hardware via `probe-rs`, on a **self-hosted GitHub Actions runner** with the board permanently tethered. Adopted when project complexity (probably Phase 3+) makes regressions on hardware expensive enough to justify the setup.

Tier 0 and 1 are mandatory. Tier 2 is a planned future investment.

### 5. Tooling left deliberately unspecified

The following are *not* locked in by this ADR (deferred to a future `doc/05-ci-and-testing.md` written when the first crate lands):

- The specific task-runner (`cargo xtask` is the leading candidate; `just` is acceptable).
- The exact GitHub Actions YAML layout, action versions, cache strategy.
- The hardware platform for the self-hosted runner (Raspberry Pi, mini-PC, repurposed laptop).
- Whether to add a fast `pre-commit` hook alongside `pre-push`.
- Whether to add `cargo deny` and at what cadence.

These are tools, not decisions. The decisions above govern them.

## Why this shape

- **Quick local feedback is the highest-leverage developer ergonomic available.** CI catching a broken push is *useful*. The local hook catching it before push, in seconds, is *transformative* — it changes how often you're willing to refactor.
- **One recipe, two callers** is the only sane way to keep CI and local in sync over time. Anything else drifts.
- **The `core`/`task` split is a forcing function for testable architecture.** If you don't insist on it from day one, retrofitting it later is painful. The Embassy actor pattern already pushes us toward "task owns state, communicates via channels" — extracting the pure logic into a `core` module costs ~nothing on top.
- **HIL deferred but explicitly planned** is the honest position. Setup investment is non-trivial and the value scales with project complexity. Committing to it now without setting it up now is the right balance.

## Consequences

### What this commits us to

- Every firmware actor split into `core` + `task` from the first crate onwards.
- A committed `tools/git-hooks/pre-push` (or equivalent) and one-shot installer.
- A task-runner script that defines the full check suite, called by both hook and CI.
- A GitHub Actions workflow file from the first crate onwards. Tier 0 minimum; Tier 1 as soon as tests exist.
- Architectural discipline: if you can't write a host-runnable test for a piece of pure logic, that's a code-organisation bug to fix.

### What this rules out

- Untested numerical / algorithmic / protocol code merging to `main`.
- CI and local check suites diverging.
- Bypassing local checks silently (`--no-verify` is allowed when conscious, but the hook is not weakened to make bypass easier).
- "We'll add tests later" as a posture. Tests are part of the work, not a follow-up task.

### What stays open

- The task-runner choice (`cargo xtask` vs `just`) — picked when the first crate lands.
- The hook framework (raw git hook + installer script vs `cargo-husky` magic) — picked then too.
- The self-hosted runner hardware and setup process — Phase 2/3 problem.
- The decision to adopt `embedded-test` specifically (vs alternative HIL approaches) — Phase 2/3 problem.
- Coverage tooling — currently parked as "probably not worth it on `no_std`"; revisit if the project gets big enough.

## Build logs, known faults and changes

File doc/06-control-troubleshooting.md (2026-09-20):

# 06 — Flight Control: Troubleshooting and Tuning Field Guide

_Date: 2026-09-20_
_Status: Living document. Append as new failure modes are understood; correct entries that turn out wrong._

This is the companion to [06-control.md](06-control.md). That doc is the *map* — how a stick deflection and a batch of IMU samples become four motor commands. This doc is the *field guide* — the recurring ways the control system misbehaves, how to tell them apart, and what actually fixes each one. It exists because the same symptoms keep coming back across airframes and sessions, and each time the temptation is to re-diagnose from scratch or to blame the control code, which has repeatedly been proven correct.

Related material:

- [06-control.md](06-control.md) — the control path as implemented.
- [progress.md](progress.md) — the dated history of how each fight was won.
- ADRs [0021](decisions/0021-coordinate-frames-and-command-semantics.md) (frames/signs), [0022](decisions/0022-attitude-estimation-complementary-filter.md) (estimator), [0023](decisions/0023-motor-numbering-layout-rotation.md) (mixer), [0024](decisions/0024-control-law-angle-mode-pd.md) (control law) — the decisions.
- [`analyze`](../crates/groundstation/src/bin/analyze.rs) — the offline telemetry analyser. Every diagnosis below is read from its report.

## Why the control system is hard

Four structural reasons the same problems recur. Keep them in mind before reaching for a gain slider.

1. **The estimator matters as much as the controller.** The controller can only be as good as its idea of "level." A wrong estimate makes a perfect controller fly wrong, and no gain change fixes it. More than one "tuning" problem has turned out to live in the estimator (see the roll-oscillation entry).
2. **Observability gap.** The only motion sensor is a 6-DoF IMU — no barometer, rangefinder, flow, or GPS. Attitude is observable (gravity is an absolute reference); altitude and horizontal position are not. The craft can hold *attitude* but not *position*. This is physics, not a bug, and it caps what the control system can ever do without new sensors.
3. **The airframe leaks into the loop.** CoM offset, motor/prop asymmetry, structural flex, and motor-vibration on the IMU all show up as control symptoms. The rigid-body assumption the whole controller rests on is only as true as the airframe.
4. **Tuning is empirical and airframe-specific.** Gains are set by the mass distribution and inertia of *this* airframe. A lighter frame, a moved battery, or a new prop can invalidate a tune. There is no "correct" gain set, only one that suits the current machine.

## The one habit: capture, then analyse

Do not debug flight behaviour from memory or eyeball. Every complaint starts the same way:

1. Fly a short run with telemetry logging on; note the `telemetry-*.tsv` path.
2. From [`crates/groundstation`](../crates/groundstation): `cargo run --release --bin analyze -- <file>`.
3. Read the report. The low-rate telemetry echoes the drone's **live `ControlSystemParameters`** ([ADR 0027](decisions/0027-split-telemetry-high-low-rate.md)), so the report shows the *actual gains flown* — never debug a run without knowing its gains.

The analyser is header-driven and reports, among other things: controller-demand-vs-model reconstruction, a rest/drift diagnosis, a rate-vs-angle phase measurement, a per-axis periodogram, and flight-segment isolation. The sections below say which line to read for each symptom.

## Symptom index

| Symptom | Most likely cause | Confirm in `analyze` | Section |
|---|---|---|---|
| Veers / skirts off in one direction on takeoff | Held tilt (estimator offset) + no position hold | rest offset est vs accel; demand-vs-model +1.0 | [1](#1-veers-or-skirts-off-in-one-direction) |
| "Self-levelling doesn't work" but loop looks fine | Attitude ≠ position; drift is uncontrolled | attitude held near level, but craft translates | [1](#1-veers-or-skirts-off-in-one-direction) |
| Slow (~0.5 Hz) wallow | Too much `ki` | dominant oscillation ~0.5 Hz on the integral axis | [2](#2-oscillation-limit-cycle) |
| Fast (~3–5 Hz) ring | Too much `kp`, or estimator lag | dominant oscillation 3–5 Hz; rate-vs-angle phase | [2](#2-oscillation-limit-cycle) |
| Oscillation survives every P/D value | Estimator lag (crossover in control band) | rate leads angle by ≫ +90° | [3](#3-estimator-lag-positive-feedback) |
| Persistent lean, re-zero only helps briefly | Gyro bias leaking into the estimate | rest: accel drift ~0 but estimate drifting | [4](#4-persistent-lean-or-slow-creep) |
| Craft holds a steady tilt / needs constant trim | Real CoM or thrust imbalance | motor split; standing demand on one axis | [5](#5-com-imbalance-and-balancing) |
| Integral won't trim a known offset in a short hop | `τ = kp/ki` too large | demand trim still climbing at end of hop | [6](#6-integral-too-slow-to-trim) |
| Trim built in-hand springs the craft on release | Integrator windup against the hand | large standing demand after a cradled run | [7](#7-integrator-windup-when-held) |

---

## 1. Veers or skirts off in one direction

**Symptom.** On throttle-up the craft slides or veers off consistently one way; the pilot chops the throttle.

**First, rule out a control bug — it almost certainly is not one.** The forward control path (estimate → error → PID → demand) has been verified repeatedly: `analyze`'s demand-vs-model reconstruction returns correlation **+1.0000** with machine-precision residual. The mixer and estimator signs are bench-verified ([ADR 0023](decisions/0023-motor-numbering-layout-rotation.md)). If demand-vs-model is near +1.0, stop looking for a sign or scaling bug.

**The real mechanism — a held tilt the craft believes is level.** The controller drives the *estimate* to level. If the estimate has a static offset — say it reads 1° low on roll — then holding the estimate at zero parks the *true* attitude at ~1° of bank. A 1° tilt is `g·sin(1°) ≈ 0.17 m/s²` of sideways acceleration, and with no position feedback nothing arrests it, so the craft slides steadily one way.

**Confirm.** In the rest/drift diagnosis, compare the estimate to the accelerometer's own gravity angle (the truth reference at rest). A non-zero `est − accel` offset with near-zero drift is a static calibration/mounting offset.

**Fix.** Re-zero the IMU on a genuinely level surface (spirit-level it). This has taken the roll offset from ~1° to ~0.1° and removed the skirt. Note that a gyro-bias leak (below) will slowly re-acquire a tilt over tens of seconds, so re-zeroing buys a clean window rather than a permanent cure.

**The part re-zeroing cannot fix.** Self-levelling holds **attitude, not position**. Even a perfectly level craft drifts, because horizontal position and velocity are unmeasured. "It won't hold still on throttle alone" is not a tuning failure — it is the observability gap. The only real fixes are to *pilot* the position out by hand, or to add horizontal sensing (optical flow + a downward rangefinder). No gain change makes an attitude controller hold position.

## 2. Oscillation (limit cycle)

Read the dominant-oscillation periodogram in `analyze`. The frequency tells you which knob:

- **Slow, ~0.5 Hz wallow, on the axis that has the integral** — classic **too much `ki`**. The integral winds past the null, overshoots, winds back. Back `ki` off to the lowest value that still trims. (Historically the 0.5 Hz wallow was the `ki` ceiling; in the 2026-09-20 session `ki` up to 0.12 showed *no* wallow, so the ceiling is airframe-dependent — do not assume a fixed limit.)
- **Fast, ~3–5 Hz ring** — the attitude loop itself is marginally stable. Two causes, distinguished by the rate-vs-angle phase (section 3):
  - **Too much `kp`** — the loop crosses over with too little phase margin and rings at the crossover frequency. Lower `kp`; the ring frequency drops as you do (a confirming signature). The lower-inertia axis (usually roll) crosses first, so decouple roll and pitch gains.
  - **Estimator lag** — see section 3. If the phase is badly wrong, no `kp`/`kd` value will kill the ring; you are fighting the wrong layer.
- **Buzz in the tens of Hz** — `kd` amplifying gyro noise. Lower `kd` or the D-term filter cutoff. Note the telemetry Nyquist (~40–45 Hz) makes a peak near the ceiling unreliable; log gyro at the loop rate to resolve a true high-frequency buzz.

`kd` is easy to leave doing nothing: at the bring-up gains, D was ~70× smaller than P, so the loop was effectively pure-proportional — which *will* limit-cycle no matter how P is set. If lowering P only *moves* the oscillation rather than killing it, the missing ingredient is damping, not less P.

## 3. Estimator lag (positive feedback)

**Symptom.** A roll or pitch oscillation that survives *every* P/D value tried.

**Mechanism.** Angle is the integral of rate, so a gyro must **lead** its own attitude estimate by **+90°**. If the complementary filter's gyro/accel crossover sits inside the control band, motion-coupled accelerometer noise distorts the estimate exactly where it matters, adding phase lag. Once the excess phase pushes the rate-to-angle lead well past +90° (toward +180°), proportional feedback becomes *positive* feedback at the oscillation frequency, and the loop rings regardless of gain.

**Confirm.** `analyze` reports the rate-vs-angle phase per axis. Expect ~+90°. The roll-oscillation episode measured ~+150° — about +60° of excess phase — which was the smoking gun.

**Fix.** Move the crossover well below the control band by raising the filter coefficient α ([ADR 0022](decisions/0022-attitude-estimation-complementary-filter.md)). Raising α exposes any latent gyro bias as a steady attitude offset (`θ = α·b·dt/(1−α)`), so zero the gyro bias at startup as well — which then frees α to go lower for motion rejection with no bias penalty. This is the canonical "wrong tool, wrong layer" fix: the symptom looked like a gain problem and was an estimator problem.

**Carry-forward.** Mild estimator lag (phase > +90° but not catastrophic) is still visible in the current filter and is one of the reasons an off-CoM IMU hurts. Moving the IMU to the CoM (the next airframe) reduces the motion coupling at the source; online gyro-bias estimation is the durable software upgrade.

## 4. Persistent lean or slow creep

**Symptom.** A steady attitude offset, or a slow drift that re-zeroing cures only temporarily.

**Confirm.** Rest/drift diagnosis: if the accelerometer angle is stable (drift ~0) but the *estimate* drifts, a residual **gyro bias** is leaking through the filter. If both are stable but offset, it is a static calibration/mounting offset (section 1).

**Fix.** Re-zero clears it for a while; the bias climbs again per run (observed rising from ~0.06 to ~2.3 dps across a session), so the real fix is **online bias estimation** rather than a one-shot startup calibration. A separate, dynamic version of this — a lean that appears only when armed — is **motor-vibration rectification** on the IMU, which needs RPM-tracking notch filtering (and therefore per-motor RPM from DShot eRPM) to fix properly.

## 5. CoM imbalance and balancing

**Symptom.** The craft holds level but needs a constant trim to do it; one axis carries a standing demand; motors are visibly unequal.

**Mechanism.** A CoM offset is a steady torque. To hold level the mixer must run the motors under the heavy corner harder. The integral supplies this trim automatically (that is what it is *for*), but a large trim spends control headroom — motors under the heavy corner sit closer to saturation, leaving less authority for that axis.

**Reading the motor split.** In the `analyze` active/flight motor means, **a motor works hardest under the heaviest corner**. Use the balance lines directly:

- `front − rear` split and the standing `demand_pitch` both gauge fore-aft CoM.
- `left − right` split and standing `demand_roll` gauge lateral CoM.
- Drive both toward zero by moving mass **toward the softest (lightest) corner**.

**Method that works.** With a shapeable nose ballast (Blu-Tack), shave preferentially off the *hardest corner* — that attacks both the fore-aft and the lateral imbalance at once. The response is roughly linear in mass moved, so the change from one adjustment extrapolates the next. Target: the four motor means converge to within a few thousandths and the standing roll/pitch demands fall to near zero. Example progression from one session: front−rear split 0.075 → 0.047 → 0.025, `demand_pitch` 0.038 → 0.024 → 0.012.

**Separating CoM from a weak motor.** If a specific corner is consistently low on liftoff, it is either CoM toward that corner or a weak motor/prop on it. The **liftoff transition is the cleaner test**: the integral resets at zero throttle and takes a second or two to wind, so the way the craft tips *as it leaves the ground* shows the raw imbalance before the integral masks it. To decide which: balance the bare frame on a fingertip at the geometric centre, props off. Tips → CoM (move mass). Sits level → motor/prop (inspect that corner's prop for damage/orientation and its motor for bearing drag). A single-axis rig pivoted **on the CoM** is the safe way to see true closed-loop response — a pendulum-stable rig (pivot below CoM) flatters the controller and hides instability; a neutral one shows the truth.

## 6. Integral too slow to trim

**Symptom.** A known offset (e.g. a CoM lean) is not trimmed out within a short hop, even though the integral is "working."

**Mechanism.** With centred sticks the integral clears a steady offset first-order, with time constant:

$$\tau = \frac{k_p}{k_i}$$

The integral is stored in contribution units (`I += ki · error/max_tilt · dt`, output adds `I` directly), which makes the accumulation loop-rate-independent and live-`ki` retuning bumpless. At the bring-up `ki = 0.02`, `τ ≈ 5.5–7.5 s` — 95% correction takes ~3τ ≈ 17–22 s, far longer than a short hop. And the integral **resets to zero at zero throttle** (anti-windup, [ADR 0024](decisions/0024-control-law-angle-mode-pd.md)), so every chop throws away what it built.

**Fix.** Raise `ki` so `τ ≈ 1–2 s` (e.g. `ki ≈ 0.07` against `kp` 0.11–0.15). Then the trim builds within a few seconds of hover. `ki` is a *pre-flight* setting — dial it on the ground, no in-flight interaction needed. Raise it incrementally and watch the periodogram for the slow wallow of section 2. Note the trim *value* the integral converges to is set by the airframe's physics, not by `ki` — a higher `ki` reaches the same trim faster, it does not change it.

**Design note.** The `throttle == 0` reset is deliberate (it stops windup on the bench and between arms). If you want a trim to persist across brief throttle chops for a series of hops, the refinement is to reset **only when disarmed** rather than on every zero-throttle sample — a small control-law change with a safety angle worth recording in [ADR 0024](decisions/0024-control-law-angle-mode-pd.md) if adopted.

## 7. Integrator windup when held

**Symptom.** After tuning or trimming with the craft cradled in hand, it lurches one way the instant it is released.

**Mechanism.** Holding the craft — even loosely, even at non-zero throttle — constrains its attitude. The control loop cannot null the error by rotating the craft (your hand prevents it), so the integrator keeps accumulating against whatever tilt your hand imposes. It winds up a large trim for that held attitude. On release, the over-wound trim has nothing opposing it and springs the craft that way. If you cradle it slightly nose-down, it winds a nose-up trim and pitches up on release.

**Consequence.** You cannot get a valid free-flight trim while holding the craft. The integral must wind against the *real* free-flight dynamics. This is why real flight controllers gate or freeze the integrator until the craft is detected airborne — the `throttle == 0` reset is a crude version, defeated by holding at non-zero throttle.

**Fix.** Trim and tune the integral in free flight (accept a couple of seconds of drift while it winds), or on a CoM-pivoted rig that frees the axis without constraining it. Do not judge a trim from a cradled run.

## Quantitative relationships worth keeping

- **Integral trim time constant:** `τ = kp / ki`. Set `ki` for `τ ≈ 1–2 s`.
- **Estimator health:** a gyro axis must lead its own attitude estimate by **+90°**. Excess phase toward +180° is positive feedback.
- **Complementary-filter offset from bias:** `θ = α·b·dt/(1−α)` — the steady lean a residual gyro bias `b` produces, growing with α. Zero the gyro bias so α can go low.
- **Tilt-to-drift:** a held tilt `θ` gives `g·sin(θ)` lateral acceleration — ~0.17 m/s² per degree. This is why a 1° estimate offset is not cosmetic.
- **Balance:** the hardest-working motor sits under the heaviest corner; drive the front−rear and left−right splits (and the standing demands) to zero.

## Reference points (airframe-specific — do not treat as universal)

- **Known-good old/heavier micro:bit frame (2026-09-20):** `kp_roll = 0.11`, `kp_pitch = 0.15`, `kd = 0.16` both axes, `ki = 0.07` both axes. The compiled-in `ControlSystemParameters::default()` is *hotter* than this on roll — a fresh boot without a live push or a flash-saved tune ([ADR 0025](decisions/0025-persist-control-parameters-flash.md)) runs hot.
- **Any new frame needs a fresh tune.** A lighter frame has lower inertia, so the same `kp` drives it harder — expect to pull `kp` down and scale `ki` with it to keep `τ ≈ 2 s`. Re-zero the IMU on a level surface before the first hop.
- **Roll vs pitch asymmetry.** A frame long in one axis has unequal inertia (`I_yy ≠ I_xx`); the lighter axis wants gentler gains. Decouple roll and pitch rather than sharing a gain.

## Open carry-forwards

- **Estimator lag** — the complementary filter still shows mild excess phase; IMU-near-CoM and online bias estimation are the fixes ([ADR 0022](decisions/0022-attitude-estimation-complementary-filter.md)).
- **Gyro bias climbing per run** — points at online bias estimation over one-shot startup calibration.
- **Motor-vibration rectification** — an armed-only lean; needs RPM-tracking notch filtering, gated on DShot eRPM.
- **Position drift** — unfixable without horizontal sensing; the ceiling on any "hover" ambition until a rangefinder/flow sensor is added.

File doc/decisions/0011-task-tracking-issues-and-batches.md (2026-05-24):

# ADR 0011 — Task tracking: GitHub Issues as canonical backlog, batched filing

- **Status:** Accepted
- **Date:** 2026-05-24
- **Related:** [ADR 0007](0007-testing-and-ci-strategy.md), closed issue [#2](https://github.com/neilpate/Drone/issues/2)

## Context

By 2026-05-24 the project has accumulated enough deferred work that "where do TODOs live" has become a real question. The candidates that surfaced:

- Inline `// TODO:` comments in source.
- A `TODO.md` at the repo root.
- A "Next session" / "Next open questions" section inside `AGENTS.md`.
- GitHub Issues.
- A GitHub Projects v2 kanban board, optionally with custom fields and automations.

Three of the four wrong answers had already been tried in some form. `AGENTS.md` "Next session" grew during the first hardware-bring-up session and became a stale duplicate of conversational state within hours. Inline `// TODO:` is fine for hyper-local notes but loses cross-cutting context. A `TODO.md` competes with the issue tracker for authority and loses every time.

The remaining question was the relationship between **issues** and **a Projects board** — and, just as important, **how aggressively to file work upfront**.

A separate failure mode worth naming: backlog inflation. Project-management dogma encourages capturing every conceivable future task so "nothing is lost". For a one-person hobby project on a multi-year horizon, an exhaustively pre-populated backlog goes stale faster than it gets worked, becomes a source of guilt rather than progress, and crowds out the few items that actually matter this week.

The author explicitly does not want Scrum, sprints, or time-boxed iterations — the dislike is for the ceremony and the time discipline, not for the underlying idea of working in coherent batches.

## Decision

### 1. GitHub Issues are the canonical backlog

Every piece of work that is worth capturing **outside of an inline `// TODO:`** is filed as an issue in `neilpate/Drone`. This includes:

- Features to implement.
- Bugs to fix.
- Refactors to do.
- Documentation / ADRs to write.
- Investigation tasks ("scope X", "decide between Y and Z").

Issues are the *only* place this kind of work lives. `AGENTS.md`, chat scrollback, source comments, sticky notes, and ad-hoc lists are not substitutes.

Closing an issue is the record that the work is done. The closing comment captures the resolution where it can be re-read in context, not in a commit message detached from the conversation that produced the decision.

### 2. Projects v2 board (#5) is a kanban *view*, not a separate backlog

The Projects v2 board at <https://github.com/users/neilpate/projects/5> exists to make the current working set visually trackable (Todo / In Progress / Done columns). It holds **a subset of issues**, manually curated.

Implications:

- Issues are not auto-added to the board. The "Auto-add to project" workflow is deliberately **not** enabled. Friction is the curation mechanism: items reach the board because they are actively being worked or actively next, not because they exist.
- No custom Project fields. Phase and area are expressed via labels, which work on issues, PRs and project items equally. Duplicating the same dimension into Project fields would create two truths.
- The default workflows that *are* enabled (closing an issue → Status=Done on the board, Status=Done → close the issue, etc.) keep the board honest without manual upkeep.

### 3. Labels are the cross-cutting taxonomy

Issues are sliced by **labels**, not by folders, milestones or Project fields. The seed taxonomy:

- **Phase**: `phase-1`, `phase-2`, ..., `phase-5`. One per issue; identifies *when* the work belongs in the milestone plan ([00-vision.md](../00-vision.md)).
- **Area**: `area:firmware`, `area:hardware`, `area:doc`, `area:tooling`. One or more per issue; identifies *what part of the system* is touched.
- Plus the GitHub defaults (`bug`, `enhancement`, `documentation`, ...).

Labels are added when they earn their keep. A label nobody filters on is noise. New labels are created when an issue genuinely doesn't fit any existing one — not pre-emptively.

### 4. Batched filing, not upfront enumeration

The backlog is **not** populated up-front for the whole project. The discipline is:

- Pick the next coherent chunk of work — a small handful of related issues (typically 2–6) that together push the system to a meaningful next state.
- File those issues. Add them to the board (Todo).
- Work them.
- When the batch is done (board is empty or near-empty), repeat: pick the next chunk, file, work.

This is sprint-shaped without being sprint-timed. The batch size is constrained by "how much can be reasoned about in one sitting", not by a calendar. There is no commitment, no review ceremony, no retrospective. The board being empty is the usual signal that triggers the next planning conversation.

"Batched" is a floor, not a ceiling. Nothing prevents a deliberate planning session that files a larger run of issues at once — e.g. when starting a new phase, scoping a self-contained subsystem, or after a design discussion that surfaced a clear set of follow-ups. The rule is that the issues filed in such a session are **issues already understood well enough to work**, not speculative captures. A planning session that files ten genuinely-ready issues is fine; one that files ten "we might want to look at this someday" issues is the backlog-inflation antipattern this ADR exists to prevent.

Things to **avoid**:

- Capturing every speculative future task "so we don't forget it". Speculative work goes in chat, ADRs (if it's a real design question), or simply in the author's head. If it matters, it will resurface when the next batch is being planned.
- Long-lived issues that drift across phases. An issue that has been open for a month without progress is a smell — either close it as "not now", break it down, or fold it into the current batch.
- Mixing batches. The board should reflect *one* working theme at a time. Two parallel themes are a sign the batch was too ambitious.

### 5. `AGENTS.md` keeps narrative context only

`AGENTS.md` is no longer a TODO tracker. It keeps:

- High-signal narrative state (vision pointers, scope guardrail, working style, glossary).
- The decisions log (an index of ADRs, not a TODO list).
- The "Next open questions" section, which is for **open design questions awaiting a decision**, not for "things to do". An open question becomes an ADR when answered; it becomes an issue when it turns into actionable work.
- A pointer to the issue tracker and the board, so a stranger landing in cold knows where the backlog actually lives.

## Consequences

**Positive.**

- One source of truth for work. Anyone (or any future assistant) reading the repo learns the convention from `AGENTS.md` and finds the live state under `/issues` and `/projects/5`.
- The board reflects current focus, not exhaustive intent. Empty columns are normal, not a failure state.
- Decisions and resolutions live attached to the work that produced them (issue + closing comment), not in distant commit messages.
- The author's stated dislike of Scrum is respected: no time-boxes, no ceremony, no velocity tracking.

**Negative.**

- Filing an issue is a small overhead. The compensating discipline is to **not** file issues for trivia — inline `// TODO:` is the right tool for "rename this variable when we touch this code next".
- Curating board membership manually is more work than auto-add. Accepted on purpose: the friction is the feature.
- Cross-project visibility is weaker than a single huge backlog. Accepted because for a one-person project, "visibility" mostly means "what should I work on next", and the board answers that.

**Operational notes.**

- A new issue: `gh issue create --repo neilpate/Drone --title "..." --body-file <file> --label "<labels>"`. Body in a file avoids PowerShell here-string fragility with `gh`.
- Add to board: `gh project item-add 5 --owner neilpate --url <issue-url>`.
- Set status: needs the field IDs (`gh project field-list 5 --owner neilpate --format json`) and `gh project item-edit ...`. A small wrapper script may be worth writing if the friction becomes real — see `area:tooling`.
- Closing an issue with a substantive resolution: `gh issue close N --repo neilpate/Drone --comment (Get-Content -Raw <file>.md)`.

## Alternatives considered

**`TODO.md` at repo root.** Rejected. Creates a second source of truth in conflict with the issue tracker; goes stale; not addressable from outside the workspace.

**A "Next session" section in `AGENTS.md`.** Tried (briefly, 2026-05-23). Rejected (2026-05-24, this ADR). Duplicates the issue list, immediately gets out of sync with chat, and pollutes a file whose job is narrative.

**Issues only, no Projects board.** Viable. Rejected because a visual kanban genuinely helps see "what's now vs. what's queued vs. what's done" at a glance, especially when work spans several days. The board's cost (one manual `item-add` per tracked issue) is low.

**Projects board with full custom-field schema (`Phase`, `Area`, `Priority`, `Estimate`, ...) and auto-add automations.** Rejected as over-engineering for a one-person project. Custom fields duplicate labels; auto-add eliminates the curation that the board's value depends on. Reconsider if the project ever grows past one contributor.

**Pre-populate the full project backlog up front.** Rejected. Backlog inflation is a known failure mode; speculative work is not work.

**Time-boxed sprints / Scrum.** Rejected by user preference. The batched-but-not-timed flow described above captures the useful part (working in coherent chunks) without the ceremony.

## References

- Closed issue [#2](https://github.com/neilpate/Drone/issues/2) — original scoping conversation and decision.
- [AGENTS.md](../../AGENTS.md) — "Backlog and task tracking" section points here.
- Project board: <https://github.com/users/neilpate/projects/5>.

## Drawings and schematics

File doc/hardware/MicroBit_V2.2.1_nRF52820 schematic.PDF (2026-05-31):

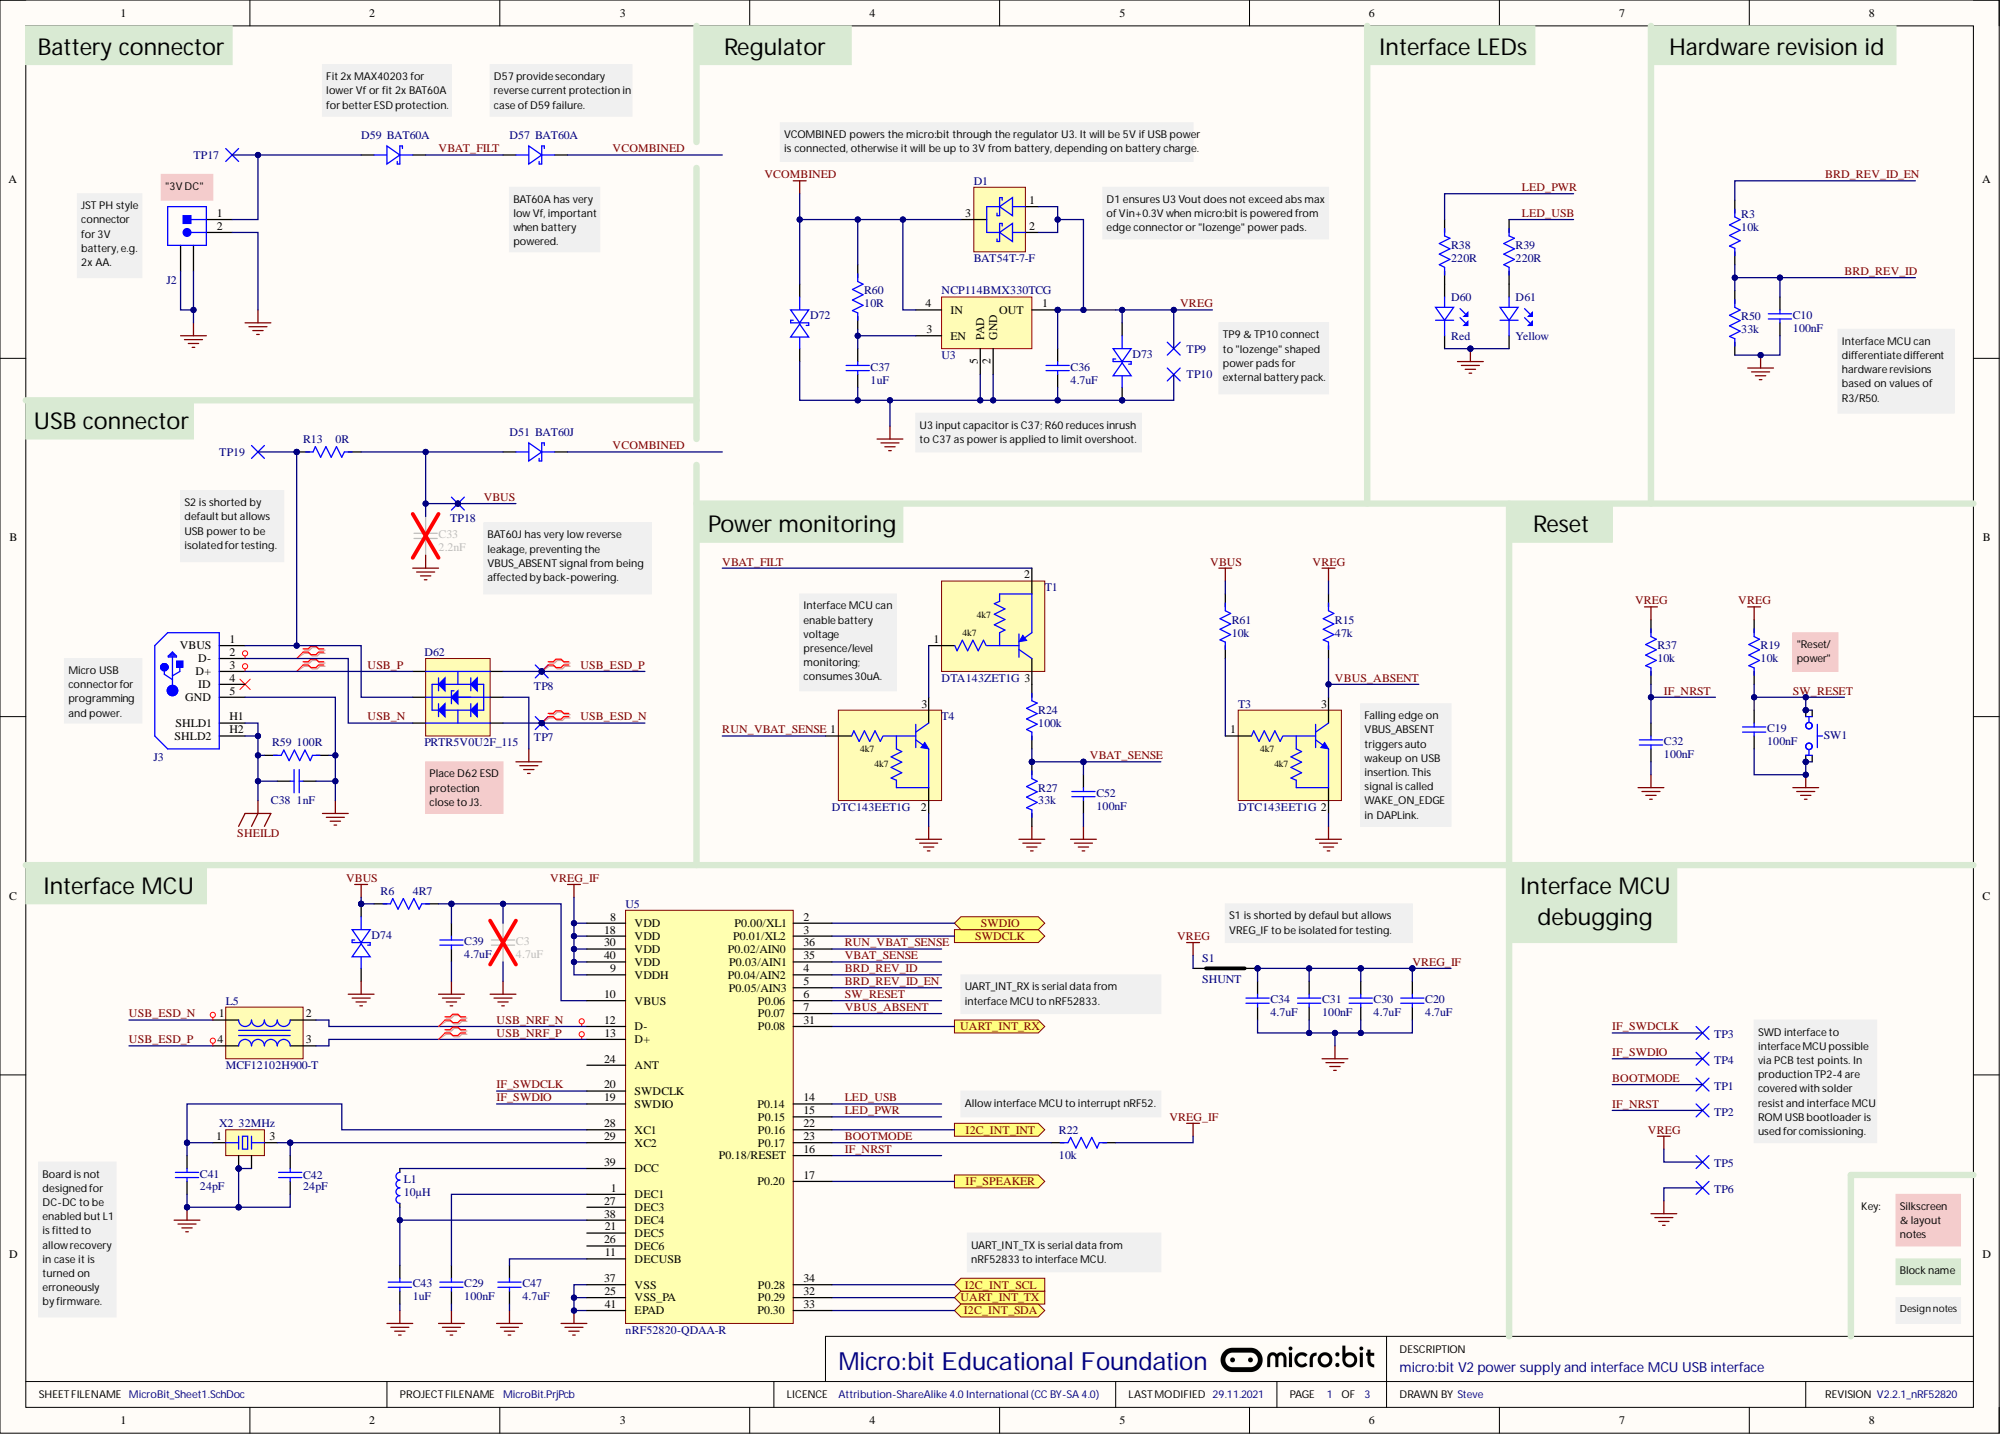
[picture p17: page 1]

Fit 2x MAX40203 for
lower Vf or fit 2x BAT60A
for better ESD protection.

D57 provide secondary
reverse current protection in
case of D59 failure.

VCOMBINED powers the micro:bit through the regulator U3. It will be 5V if USB power
is connected, otherwise it will be up to 3V from battery, depending on battery charge.

D1 ensures U3 Vout does not exceed abs max
of Vin+0.3V when micro:bit is powered from
edge connector or "lozenge" power pads.

Interface MCU can
differentiate different
hardware revisions
based on values of

USB connector

U3 input capacitor is C37; R60 reduces inrush
to C37 as power is applied to limit overshoot.

S2 is shorted by
default but allows
USB power to be
isolated fortesting.

BAT60J has very low reverse
leakage, preventing the
VBUS_ABSENT signal from being
affected by back-powering.

S1 is shorted by defaul but allows
VREG_IF to be isolated for testing.

VDD 18
VDD 30
VDD 40 | VBAT_SENSE

UART_INT_RX is serial data from
interface MCU to nRF52833.

SWD interface to
interface MCU possible
via PCB test points. In
production TP2-4 are
covered with solder
resist and interface MCU
ROM USB bootloader is
used for comissioning.

Allow interface MCU to interrupt nRF52.

L1 Board is not
designed for
enabled but L1
is fitted to
allow recovery
in case it is
turned on
erroneously

UART_INT_TX is serial data from
nRF52833 to interface MCU.

Micro:bit Educational Foundation

DESCRIPTION
micro:bit V2 power supply and interface MCU USB interface

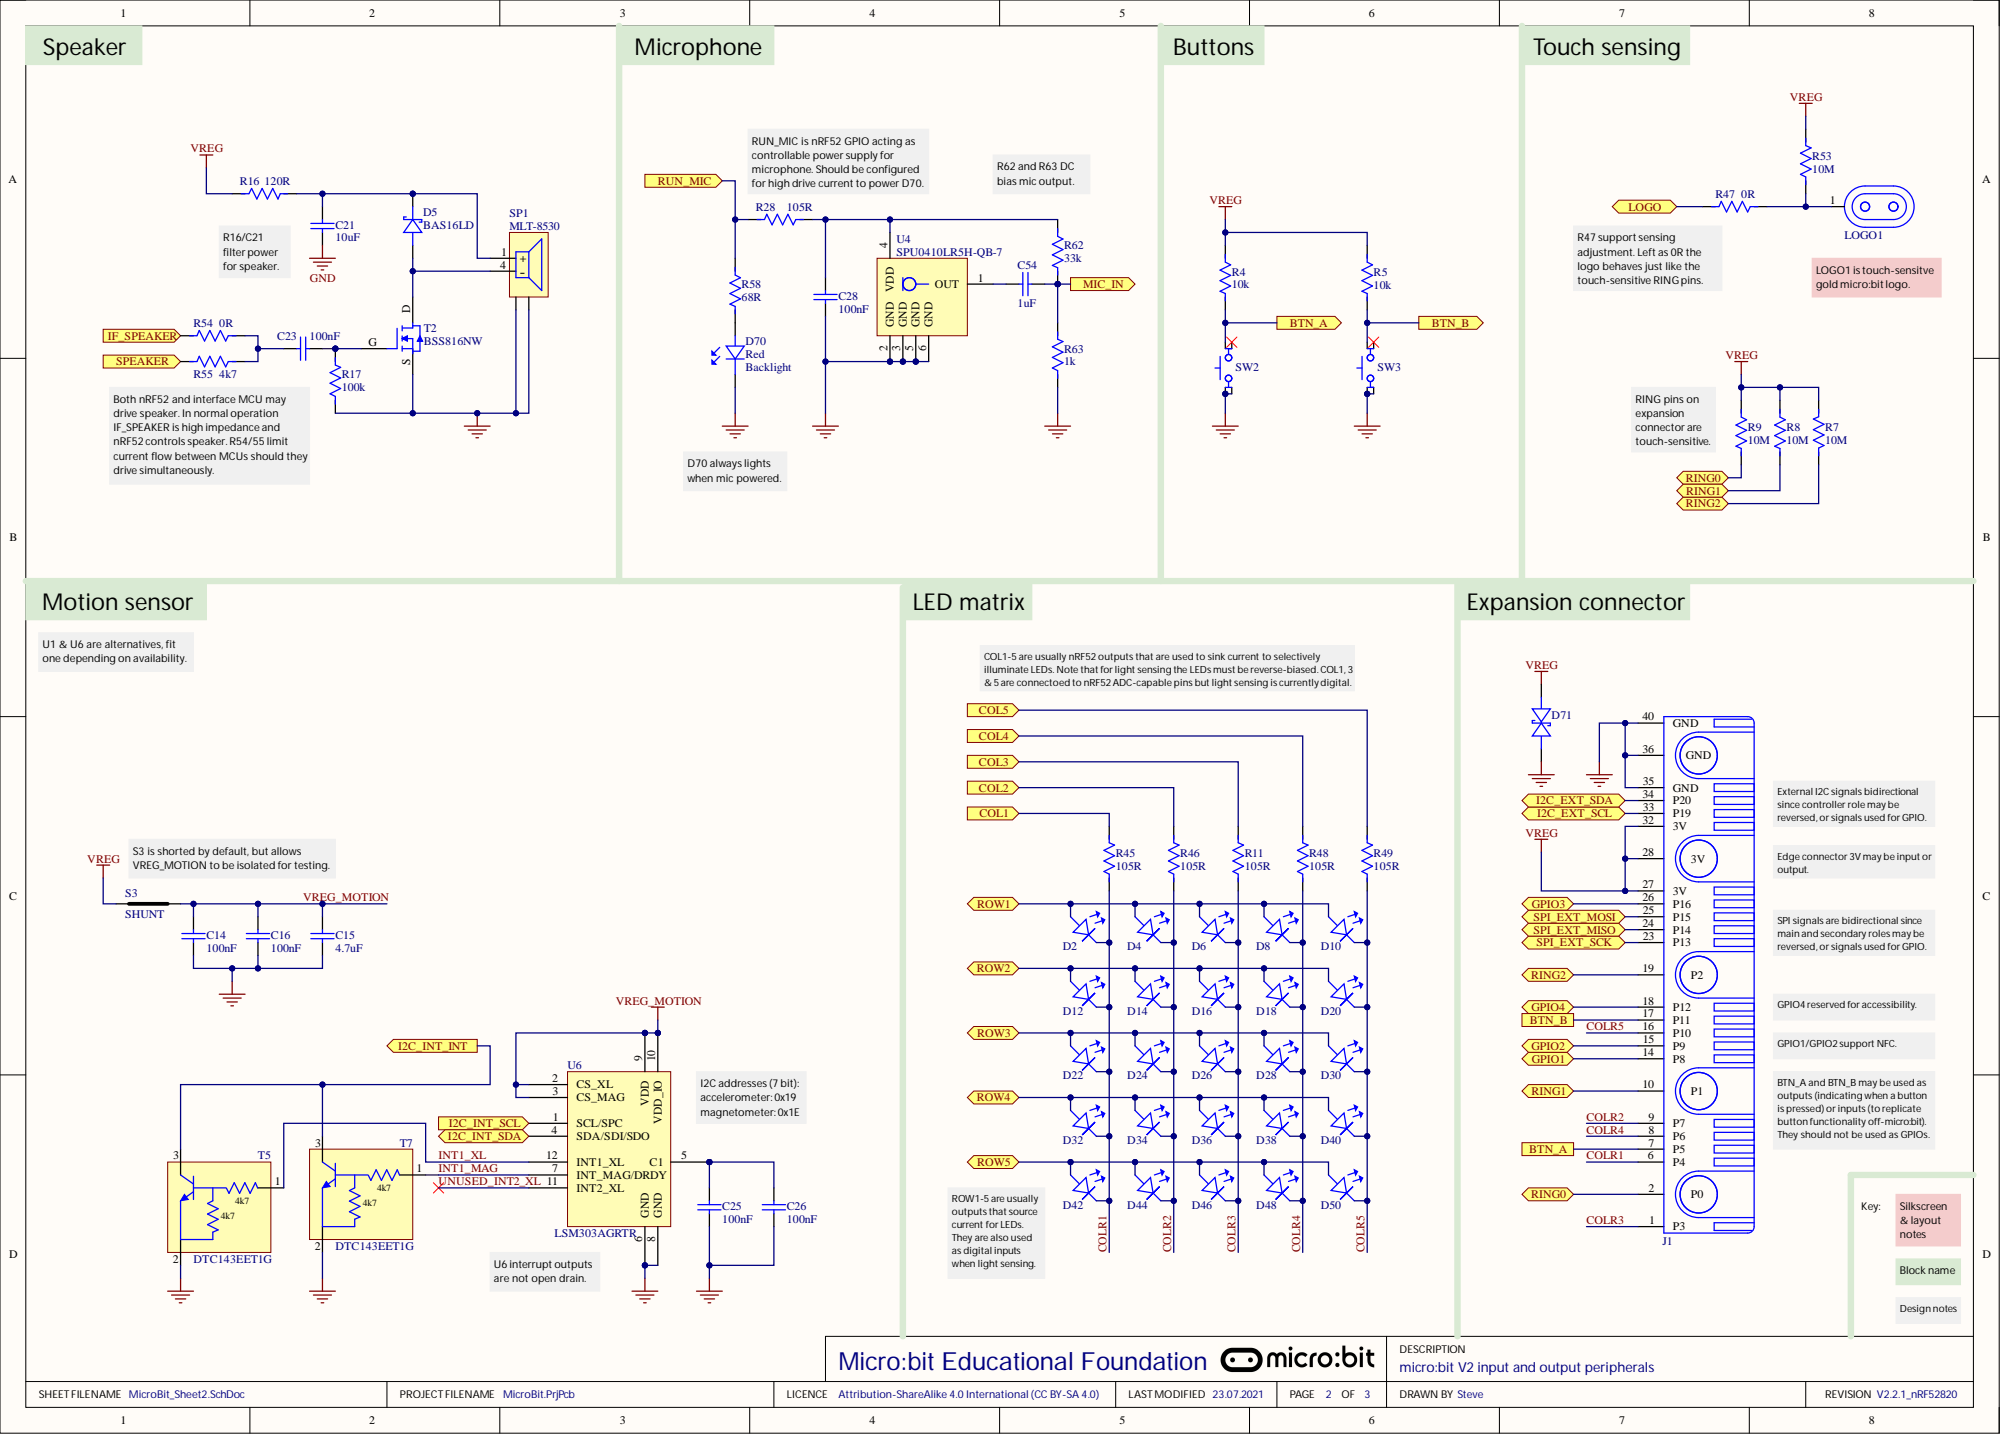
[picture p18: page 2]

RUN_MIC is nRF52 GPIO acting as
controllable power supply for
microphone. Should be configured
for high drive current to power D70.

R47 support sensing
adjustment. Left as 0R the
logo behaves just like the
touch-sensitive RING pins.

Both nRF52 and interface MCU may
drive speaker. In normal operation
IF_SPEAKER is high impedance and
nRF52 controls speaker.R54/55 limit
current flow between MCUs should they

U1 & U6 are alternatives, fit
one depending on availability.

COL1-5 are usually nRF52 outputs that are used to sink current to selectively
illuminate LEDs. Note that for light sensing the LEDs must be reverse-biased. COL1, 3
& 5 are connectoed to nRF52ADC-capable pins but light sensing is currently digital.

External I2C signals bidirectional
since controller role may be
reversed, or signals used for GPIO.

S3 is shorted by default, but allows
VREG_MOTION to be isolated for testing.

Edge connector 3V may be input or
output.

SPI signals are bidirectional since
main and secondary roles may be

BTN_A and BTN_B may be used as
outputs (indicating when a button
is pressed) or inputs (to replicate
button functionality off-micro:bit).
They should not be used as GPIOs.

ROW1-5 are usually
outputs that source
current for LEDs.
They are also used
as digital inputs
when light sensing.

U6 interrupt outputs
are not open drain.

DESCRIPTION
micro:bit V2 input and output peripherals

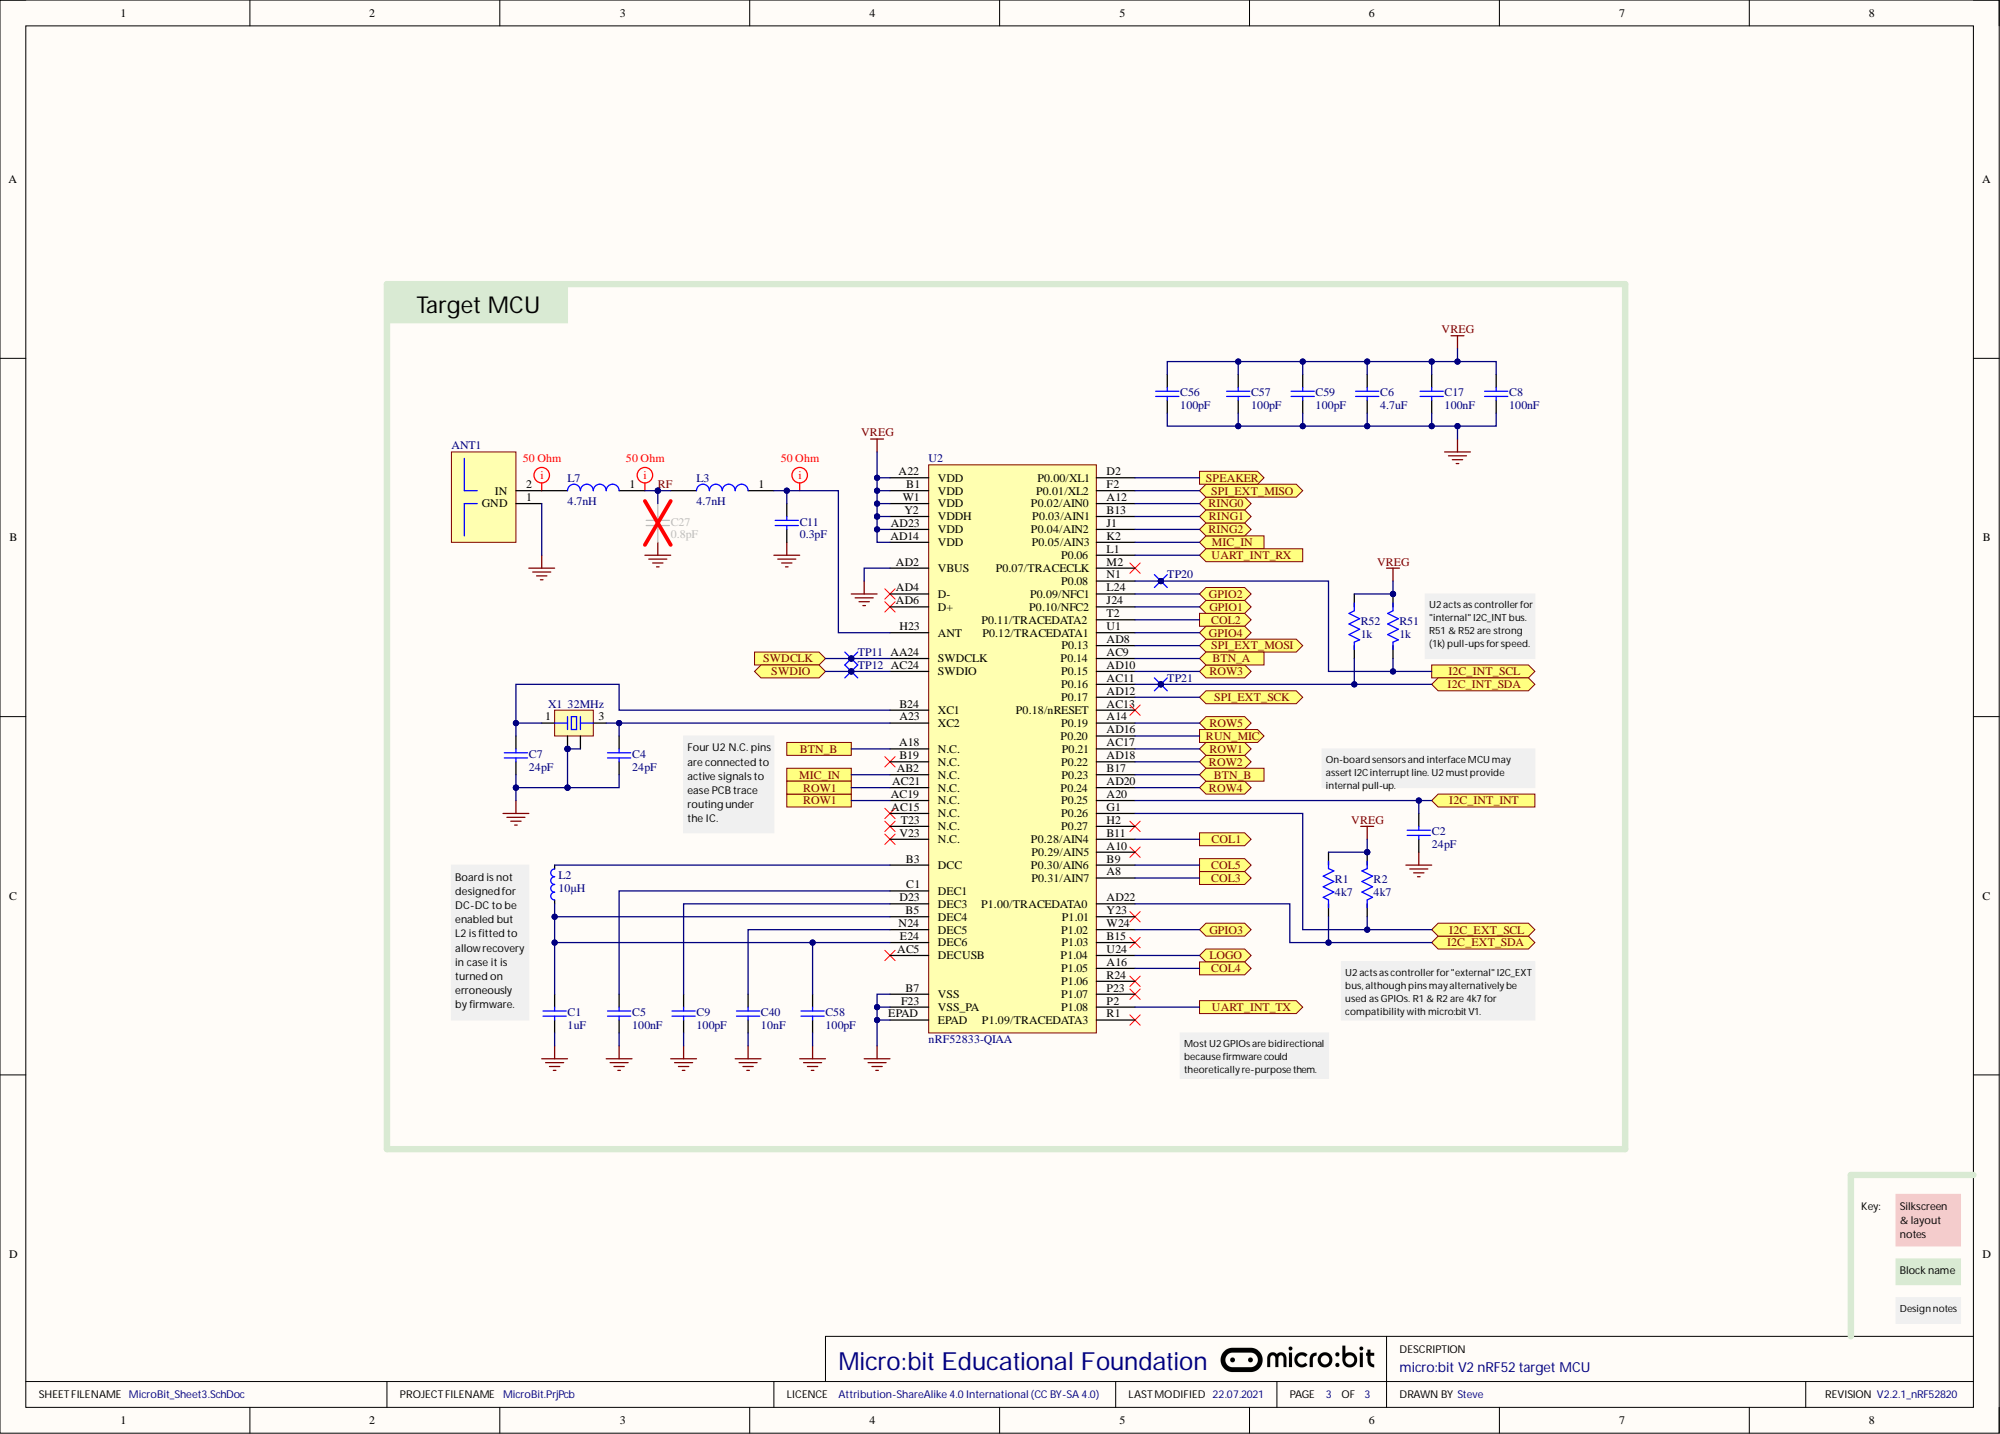
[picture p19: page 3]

Y 2
A D 2 3
A D 1 4

routing under the IC.

B o a rd is no t designed fo r D C-D C t o be ena bled but L2 is fit ted t o allow recovery in c a se it is turned on er roneously by fir mwa re. | L 2

Y 2 3 | GPIO 3

N 2 4 | W 2 4
E 2 4 | 5
A C 5 | U 2 4 L O G O

micro:bit V2 nRF52 target MCU DESCRIPTION

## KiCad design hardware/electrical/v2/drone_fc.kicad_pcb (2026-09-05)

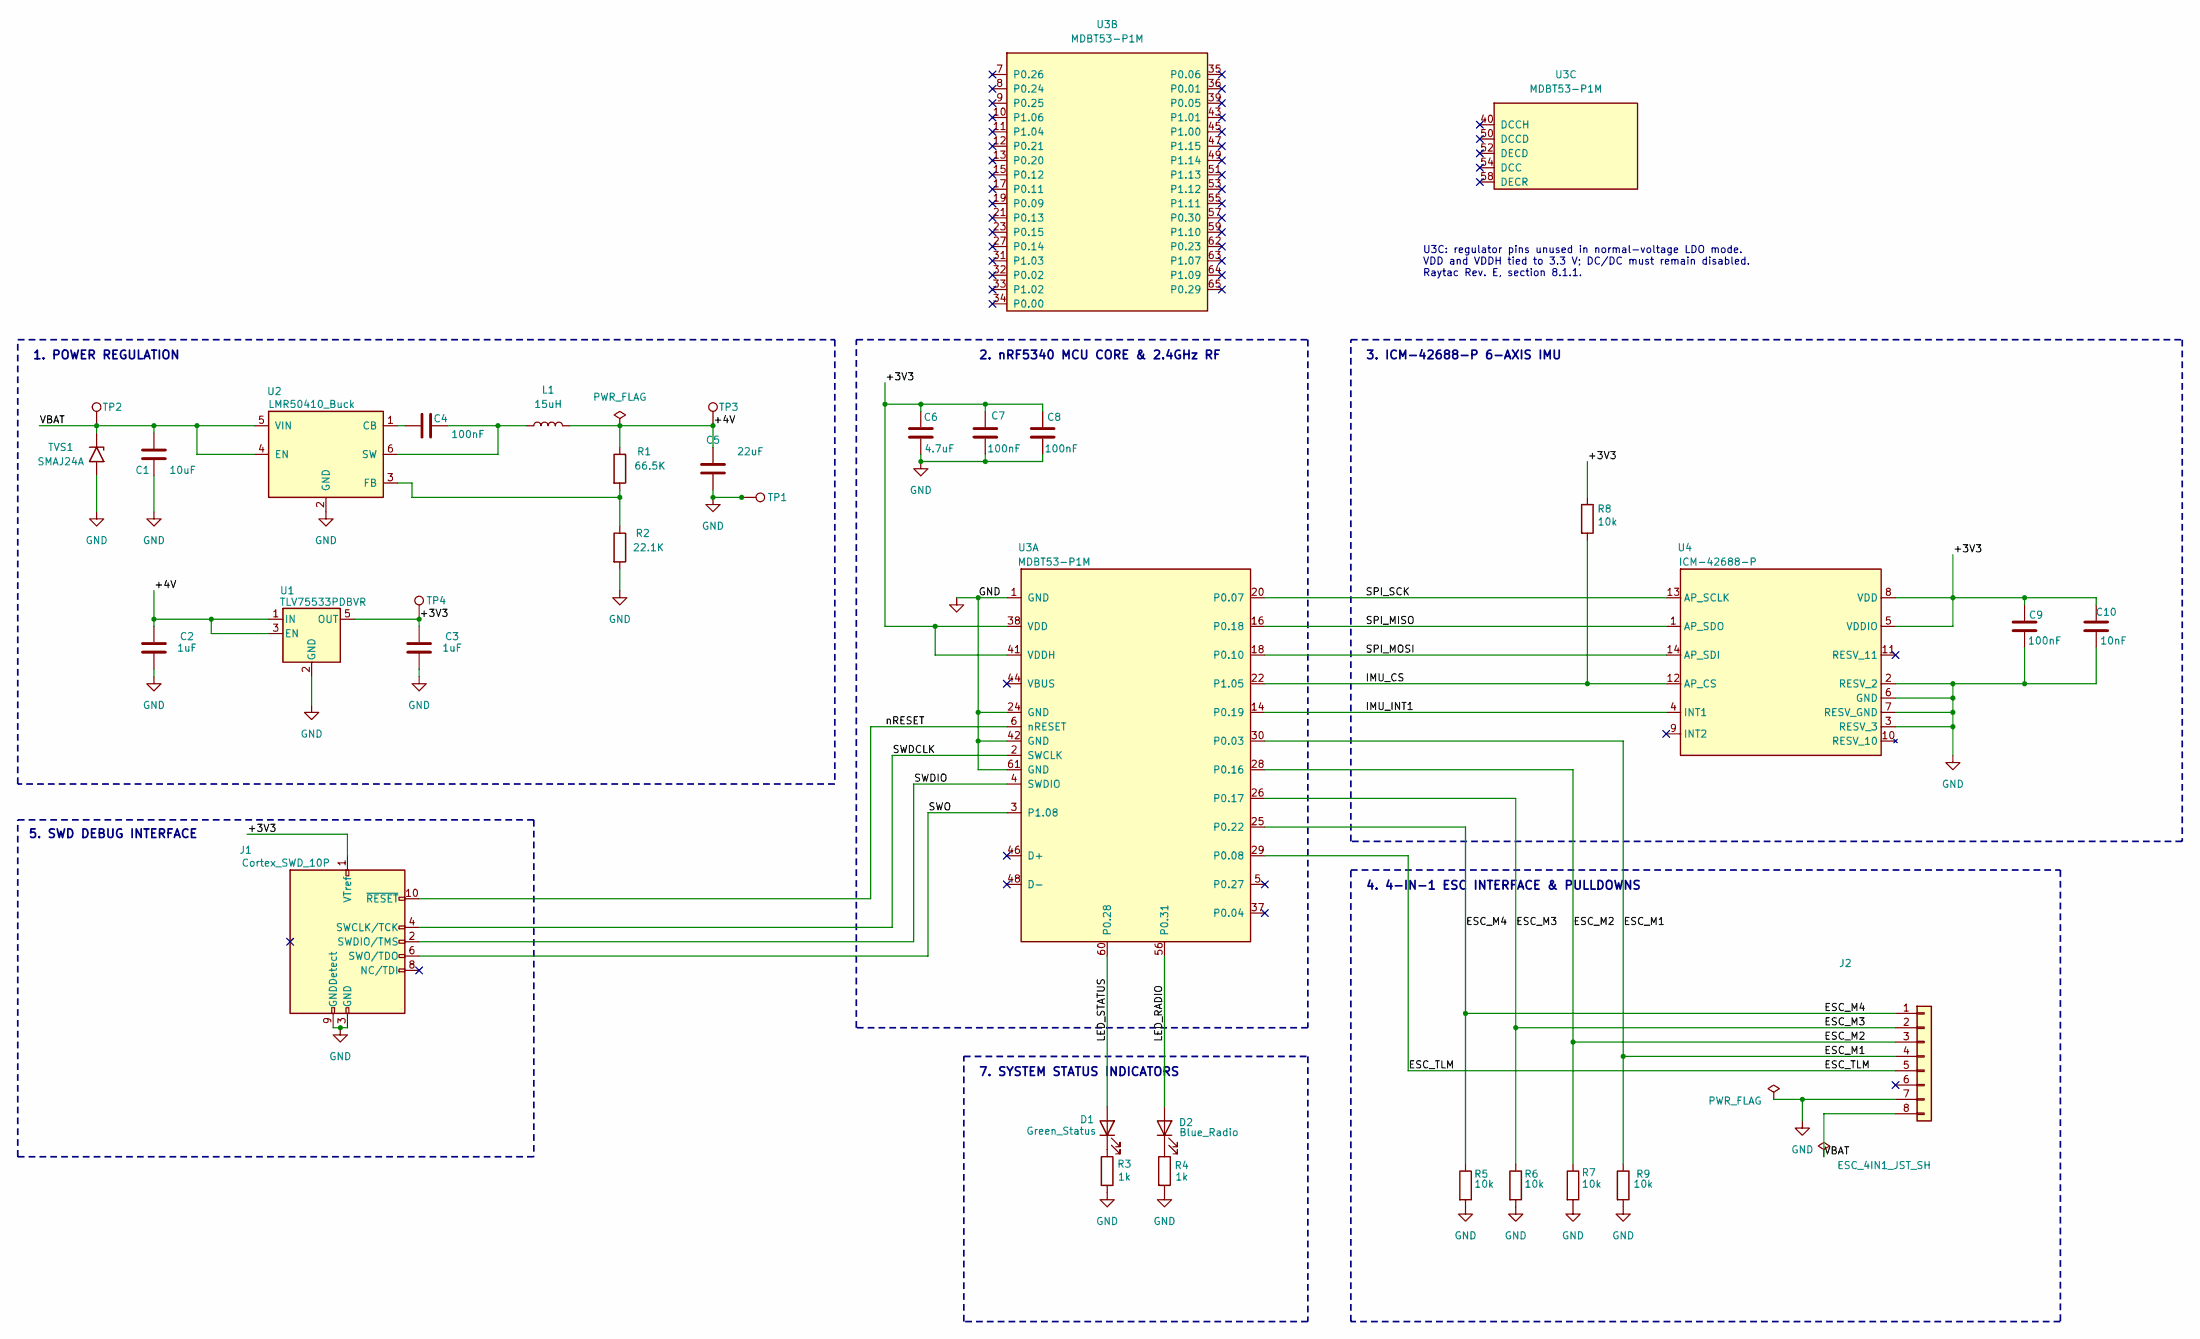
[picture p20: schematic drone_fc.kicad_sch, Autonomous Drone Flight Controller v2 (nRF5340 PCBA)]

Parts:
C1: 10uF; C_1206_3216Metric; MPN CL31B106KBHNNNE
C2, C3: 1uF; C_0402_1005Metric; MPN GRM155R61C105KA12D
C4, C7, C8, C9: 100nF; C_0402_1005Metric; MPN GRM155R71H104KE14D
C5: 22uF; C_0805_2012Metric; MPN GRM21BR61A226ME44
C6: 4.7uF; C_0603_1608Metric; MPN GRM188R61A475KAAJD
C10: 10nF; C_0402_1005Metric; MPN C0402C103K5RECAUTO
D1: Green_Status; LED_0402_1005Metric; MPN LTST-C281KGKT
D2: Blue_Radio; LED_0402_1005Metric; MPN LTST-C281TBKT
J1: Cortex_SWD_10P; Tag-Connect_TC2050-IDC-NL_2x05_P1.27mm_Vertical
J2: ESC_4IN1_JST_SH; JST_SH_SM08B-SRSS-TB_1x08-1MP_P1.00mm_Horizontal; MPN SM08B-SRSS-TB
L1: 15uH; L_0805_2012Metric; MPN MLZ2012M150WT000
R1: 66.5K; R_0402_1005Metric; MPN RC0402FR-0766K5L
R2: 22.1K; R_0402_1005Metric; MPN RC0402FR-0722K1L
R3, R4: 1k; R_0402_1005Metric; MPN RC0402FR-071KL
R5, R6, R7, R8, R9: 10k; R_0402_1005Metric; MPN RC0402FR-0710KL
TP1: GND; TestPoint_Pad_D1.0mm
TP2: VBAT; TestPoint_Pad_D1.0mm
TP3: +4V; TestPoint_Pad_D1.0mm
TP4: +3V3; TestPoint_Pad_D1.0mm
TVS1: SMAJ24A; D_SMA; MPN SMAJ24A
U1: TLV75533PDBVR; SOT-23-5; MPN TLV75533PDBVR
U2: LMR50410_Buck; SOT-23-6; MPN LMR50410XDBVR
U3: MDBT53-P1M; MPN MDBT53-P1M
U4: ICM-42688-P; LGA-14_2.5x3.0mm_P0.5mm_ICM42688P; MPN ICM-42688-P

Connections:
/+3V3: C3.1, C6.1, C7.1, C8.1, C9.1, C10.1, J1.1 (VTref), R8.1, TP4.1 (1_1), U1.5 (OUT), U3.38 (VDD), U3.41 (VDDH), U4.5 (VDDIO), U4.8 (VDD)
/+4V: C2.1, C5.1, L1.2, R1.1, TP3.1 (1_1), U1.1 (IN), U1.3 (EN)
/ESC_M1: J2.4, R9.1, U3.30 (P0.03)
/ESC_M2: J2.3, R7.1, U3.28 (P0.16)
/ESC_M3: J2.2, R6.1, U3.26 (P0.17)
/ESC_M4: J2.1, R5.1, U3.25 (P0.22)
/ESC_TLM: J2.5, U3.29 (P0.08)
/IMU_CS: R8.2, U3.22 (P1.05), U4.12 (AP_CS)
/IMU_INT1: U3.14 (P0.19), U4.4 (INT1)
/LED_RADIO: D2.2 (A), U3.56 (P0.31)
/LED_STATUS: D1.2 (A), U3.60 (P0.28)
/SPI_MISO: U3.16 (P0.18), U4.1 (AP_SDO)
/SPI_MOSI: U3.18 (P0.10), U4.14 (AP_SDI)
/SPI_SCK: U3.20 (P0.07), U4.13 (AP_SCLK)
/SWDCLK: J1.4 (SWCLK/TCK), U3.2 (SWCLK)
/SWDIO: J1.2 (SWDIO/TMS), U3.4 (SWDIO)
/SWO: J1.6 (SWO/TDO), U3.3 (P1.08)
/VBAT: C1.1, J2.8, TP2.1 (1_1), TVS1.1 (A1), U2.4 (EN), U2.5 (VIN)
/nRESET: J1.10 (~RESET), U3.6 (nRESET)
GND: C1.2, C2.2, C3.2, C5.2, C6.2, C7.2, C8.2, C9.2, C10.2, J1.3 (GND), J1.5 (GND), J1.9 (GNDDetect), J2.7, R2.2, R3.2, R4.2, R5.2, R6.2, R7.2, R9.2, TP1.1 (1_1), TVS1.2 (A2), U1.2 (GND), U2.2 (GND), U3.1 (GND), U3.24 (GND), U3.42 (GND), U3.61 (GND), U4.2 (RESV_2), U4.3 (RESV_3), U4.6 (GND), U4.7 (RESV_GND)
unnamed: D1.1 (K), R3.1
unnamed: D2.1 (K), R4.1
unnamed: C4.2, U2.1 (CB)
unnamed: R1.2, R2.1, U2.3 (FB)
unnamed: C4.1, L1.1, U2.6 (SW)

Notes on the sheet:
2. nRF5340 MCU CORE & 2.4GHz RF
5. SWD DEBUG INTERFACE
3. ICM-42688-P 6-AXIS IMU
4. 4-IN-1 ESC INTERFACE & PULLDOWNS
1. POWER REGULATION
7. SYSTEM STATUS INDICATORS
U3C: regulator pins unused in normal-voltage LDO mode. VDD and VDDH tied to 3.3 V; DC/DC must remain disabled. Raytac Rev. E, section 8.1.1.

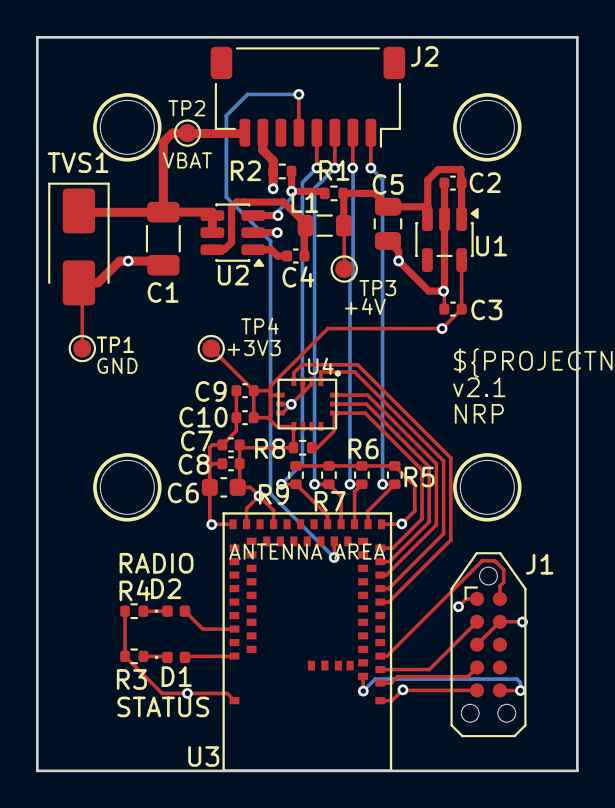
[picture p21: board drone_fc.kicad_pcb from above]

Board: 4 copper layers, 30.0 x 40.8 mm, 37 parts (0 on the bottom side), 25 nets.

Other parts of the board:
H1, H2, H3, H4: M2 soft mount; MountingHole_3.0mm

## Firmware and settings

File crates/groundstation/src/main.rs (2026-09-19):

//! Ground station: throttle + roll/pitch/yaw command sender + telemetry plotter.
//!
//! Sends control values as postcard + COBS framed `Command` messages over a
//! serial port at 115 200 8N1, and receives postcard + COBS framed
//! `TelemetryFrame` on the same port. A single I/O thread handles both
//! directions (see `serial_io_thread`) and forwards each decoded frame to the
//! UI thread, which merges it into a running view, appends the high-rate
//! channels to a set of time series and draws them in a live plot.
//! Each signal can be shown or hidden with a checkbox.

use std::collections::VecDeque;
use std::fs::File;
use std::io::{BufWriter, Write};
use std::sync::mpsc;
use std::thread;
use std::time::{Duration, Instant, SystemTime, UNIX_EPOCH};

use postcard::accumulator::{CobsAccumulator, FeedResult};

use firmware_types::{
    Acceleration, AngularRate, Attitude, COMMAND_FRAME_MAX_SIZE_BYTES, Command, ControlMode,
    ControlSystemParameters, ControllerDemand, CpuLoad, DroneState, ESCTelemetry, ImuData,
    MotorCommand, PilotCommand, PitchCommand, RollCommand, TO_GROUNDSTATION_MAX_SIZE_BYTES,
    TelemetryFrame, TelemetryFrameHighRate, TelemetryFrameLowRate, Temperature, ThrottleCommand,
    ToGroundStation, YawCommand,
};

use groundstation::{
    commands_match, drone_state_code, encode_command, stick_to_deflection, trigger_to_throttle,
};

use eframe::egui;
use egui_plot::{Corner, Legend, Line, Plot, PlotPoints};
use gilrs::{Axis, Button, EventType, GamepadId, Gilrs};

mod attitude_view;
use attitude_view::AttitudeView;

const MAX_SEND_BUFFER_SIZE: usize = COMMAND_FRAME_MAX_SIZE_BYTES;

/// Maximum number of samples retained per signal (the last N frames).
const MAX_POINTS: usize = 10_000;

/// Maximum number of in-flight (sent but not yet echoed) commands tracked for
/// the round-trip latency measurement. Bounds memory if telemetry never
/// matches (e.g. the drone is holding zero throttle while we keep sending).
const MAX_PENDING: usize = 512;

/// Smoothing factor for the exponential moving average of the round-trip time.
const RTT_EMA_ALPHA: f64 = 0.2;

/// Storage key under which the configured serial port name is persisted
/// between runs.
const PORT_STORAGE_KEY: &str = "port_name";

fn main() -> eframe::Result<()> {
    let options = eframe::NativeOptions {
        viewport: egui::ViewportBuilder::default().with_inner_size([900.0, 600.0]),
        ..Default::default()
    };
    eframe::run_native(
        "Drone Ground Station",
        options,
        Box::new(|cc| Ok(Box::new(App::new(cc)))),
    )
}

/// One plotted signal: a name, a colour, a visibility toggle and its samples.
#[derive(Debug)]
struct Series {
    name: &'static str,
    color: egui::Color32,
    visible: bool,
    /// `[t_seconds, value]` points in capture order.
    points: Vec<[f64; 2]>,
}

impl Series {
    fn new(name: &'static str, color: egui::Color32) -> Self {
        Self {
            name,
            color,
            visible: true,
            points: Vec::new(),
        }
    }

    /// Builder tweak: start hidden. Used for channels whose magnitude would
    /// otherwise dominate the plot's auto-scale (temperature, latency, the
    /// sequence ramp), so the user opts them in.
    fn hidden(mut self) -> Self {
        self.visible = false;
        self
    }

    fn push(&mut self, t: f64, value: f64) {
        self.points.push([t, value]);
        if self.points.len() > MAX_POINTS {
            let overflow = self.points.len() - MAX_POINTS;
            self.points.drain(0..overflow);
        }
    }
}

// Indices into `App::series`. Kept as constants so sample-pushing and drawing
// stay in sync without a map lookup.
const SERIES_THROTTLE: usize = 0;
const SERIES_ROLL: usize = 1;
const SERIES_PITCH: usize = 2;
const SERIES_YAW: usize = 3;
const SERIES_DRONE_STATE: usize = 4;
const SERIES_SEQUENCE: usize = 5;
const SERIES_TEMPERATURE: usize = 6;
const SERIES_RTT: usize = 7;
const SERIES_AVG_RTT: usize = 8;
const SERIES_CPU_LOAD: usize = 9;
const SERIES_ACCEL_X: usize = 10;
const SERIES_ACCEL_Y: usize = 11;
const SERIES_ACCEL_Z: usize = 12;
const SERIES_GYRO_X: usize = 13;
const SERIES_GYRO_Y: usize = 14;
const SERIES_GYRO_Z: usize = 15;
const SERIES_ATTITUDE_ROLL: usize = 16;
const SERIES_ATTITUDE_PITCH: usize = 17;
const SERIES_DEMAND_ROLL: usize = 18;
const SERIES_DEMAND_PITCH: usize = 19;
const SERIES_DEMAND_YAW: usize = 20;
const SERIES_MOTOR_1: usize = 21;
const SERIES_MOTOR_2: usize = 22;
const SERIES_MOTOR_3: usize = 23;
const SERIES_MOTOR_4: usize = 24;
const SERIES_GYRO_FX: usize = 25;
const SERIES_GYRO_FY: usize = 26;
const SERIES_GYRO_FZ: usize = 27;
const SERIES_ESC_TEMP: usize = 28;
const SERIES_PACK_VOLTAGE: usize = 29;
const SERIES_PACK_CURRENT: usize = 30;
const SERIES_CONSUMED: usize = 31;
const SERIES_MOTOR_1_RPM: usize = 32;
const SERIES_MOTOR_2_RPM: usize = 33;
const SERIES_MOTOR_3_RPM: usize = 34;
const SERIES_MOTOR_4_RPM: usize = 35;
/// Number of plot series; also the length of the by-series lookup table.
const SERIES_COUNT: usize = SERIES_MOTOR_4_RPM + 1;

/// Fixed width, in points, for every telemetry category box so they all align.
const TELEMETRY_BOX_WIDTH: f32 = 210.0;

/// The ground station's merged view of the latest telemetry. The drone sends
/// two interleaved frames (high-rate flight data, low-rate housekeeping); this
/// holds the most recent value of every field so the plot, table and log always
/// see a complete row. High-rate frames drive new rows; low-rate frames only
/// refresh their slower-changing fields (ADR 0027).
#[derive(Clone, Copy)]
struct TelemetryView {
    sequence_number: u32,
    drone_state: DroneState,
    control_mode: ControlMode,
    pilot_command: PilotCommand,
    cpu_load: CpuLoad,
    temperature: Temperature,
    imu: ImuData,
    filtered_angular_rate_x: AngularRate,
    filtered_angular_rate_y: AngularRate,
    filtered_angular_rate_z: AngularRate,
    attitude: Attitude,
    controller_demand: ControllerDemand,
    motor_command: MotorCommand,
    esc_telemetry: ESCTelemetry,
    /// The drone's active gains, echoed on the low-rate frame; logged as
    /// ground-truth instead of the ground station's own slider values.
    control_parameters: ControlSystemParameters,
    /// Packed firmware version (major<<16 | minor<<8 | patch), from the low-rate frame.
    firmware_version: u32,
}

impl Default for TelemetryView {
    fn default() -> Self {
        Self {
            sequence_number: 0,
            drone_state: DroneState::Initialising,
            control_mode: ControlMode::Manual,
            pilot_command: PilotCommand::default(),
            cpu_load: CpuLoad::from_percentage(0.0),
            temperature: Temperature::from_celsius(0.0),
            imu: ImuData {
                acceleration_x: Acceleration::from_g(0.0),
                acceleration_y: Acceleration::from_g(0.0),
                acceleration_z: Acceleration::from_g(0.0),
                angular_rate_x: AngularRate::from_degrees_per_second(0.0),
                angular_rate_y: AngularRate::from_degrees_per_second(0.0),
                angular_rate_z: AngularRate::from_degrees_per_second(0.0),
            },
            filtered_angular_rate_x: AngularRate::from_degrees_per_second(0.0),
            filtered_angular_rate_y: AngularRate::from_degrees_per_second(0.0),
            filtered_angular_rate_z: AngularRate::from_degrees_per_second(0.0),
            attitude: Attitude::from_degrees(0.0, 0.0),
            controller_demand: ControllerDemand::ZERO,
            motor_command: MotorCommand::ZERO,
            esc_telemetry: ESCTelemetry::default(),
            control_parameters: ControlSystemParameters::default(),
            firmware_version: 0,
        }
    }
}

impl TelemetryView {
    fn apply_high_rate(&mut self, f: &TelemetryFrameHighRate) {
        self.sequence_number = f.sequence_number;
        self.drone_state = f.drone_state;
        self.pilot_command = f.pilot_command;
        self.imu = f.imu;
        self.filtered_angular_rate_x = f.filtered_angular_rate_x;
        self.filtered_angular_rate_y = f.filtered_angular_rate_y;
        self.filtered_angular_rate_z = f.filtered_angular_rate_z;
        self.attitude = f.attitude;
        self.controller_demand = f.controller_demand;
        self.motor_command = f.motor_command;
    }

    fn apply_low_rate(&mut self, f: &TelemetryFrameLowRate) {
        self.sequence_number = f.sequence_number;
        self.cpu_load = f.cpu_load;
        self.control_mode = f.control_mode;
        self.temperature = f.temperature;
        self.esc_telemetry = f.esc_telemetry;
        self.control_parameters = f.control_parameters;
        self.firmware_version = f.firmware_version;
    }
}

/// Unpack a packed firmware version (major<<16 | minor<<8 | patch) as `vMAJOR.MINOR.PATCH`.
fn format_version(packed: u32) -> String {
    let major = (packed >> 16) & 0xFF;
    let minor = (packed >> 8) & 0xFF;
    let patch = packed & 0xFF;
    format!("v{major}.{minor}.{patch}")
}

/// Label text for a gain row, tinted amber when the slider value deviates from
/// the drone's active (last-reported) value — i.e. an unsent edit.
fn param_label(name: &str, slider: f32, drone: Option<f32>) -> egui::RichText {
    let text = egui::RichText::new(name);
    if drone.is_some_and(|d| d != slider) {
        text.color(egui::Color32::from_rgb(240, 170, 60))
    } else {
        text
    }
}

struct App {
    port_name: String,
    throttle: f32,
    roll: f32,
    pitch: f32,
    yaw: f32,
    tx: Option<mpsc::Sender<Command>>,
    telemetry_rx: Option<mpsc::Receiver<(f64, ToGroundStation)>>,
    status: String,
    start: Instant,
    series: Vec<Series>,
    last: Option<TelemetryView>,
    /// Most recent firmware version reported by the remote in its own
    /// `RemoteInfo` message, distinct from the drone version carried in
    /// telemetry. `None` until the first `RemoteInfo` arrives.
    remote_firmware_version: Option<u32>,
    /// Sent commands awaiting their echo in telemetry, with the send instant.
    /// Used to measure the end-to-end round-trip time.
    pending: VecDeque<(Instant, Command)>,
    /// Most recent measured round-trip time, in milliseconds.
    last_rtt_ms: Option<f64>,
    /// Smoothed round-trip time (exponential moving average), in milliseconds.
    avg_rtt_ms: Option<f64>,
    gilrs: Option<Gilrs>,
    active_gamepad: Option<GamepadId>,
    gamepad_name: Option<String>,
    /// Current control mode; toggled by the gamepad triangle button and sent to
    /// the drone in every command.
    control_mode: ControlMode,
    /// Control system parameters (gains, limits) sent to the drone on demand.
    params: ControlSystemParameters,
    /// True while the user is editing a slider: suspends adopting telemetry into
    /// the sliders until the drone confirms the sent value. Set on slider press,
    /// cleared when the drone's echo matches the sliders.
    params_locked: bool,
    /// Last low-rate telemetry sequence number, to detect a drone reboot (the
    /// counter resets to 0), which force-unlocks and re-syncs the sliders.
    last_control_seq: Option<u32>,
    /// Open TSV log sink while data logging is active; `None` when stopped.
    log_file: Option<BufWriter<File>>,
    /// Absolute path of the active (or most recent) log file, for the status line.
    log_path: Option<String>,
    /// Number of telemetry rows written to the current log file.
    log_rows: u64,
    /// When true, incoming telemetry is still drained and logged, but the plot
    /// series are frozen so a region can be box-zoomed and inspected without new
    /// data rescaling the view.
    paused: bool,
    /// 3D attitude renderer (mesh + camera), reused each frame.
    attitude_view: AttitudeView,
    /// Texture the attitude render is uploaded into; created on first frame.
    attitude_texture: Option<egui::TextureHandle>,
}

impl Default for App {
    fn default() -> Self {
        Self {
            port_name: "COM7".to_string(),
            throttle: 0.0,
            roll: 0.0,
            pitch: 0.0,
            yaw: 0.0,
            tx: None,
            telemetry_rx: None,
            status: "Not connected".to_string(),
            start: Instant::now(),
            series: vec![
                Series::new("Throttle (0..1)", egui::Color32::from_rgb(100, 170, 255)),
                Series::new("Roll (-1..1)", egui::Color32::from_rgb(230, 80, 80)),
                Series::new("Pitch (-1..1)", egui::Color32::from_rgb(200, 120, 255)),
                Series::new("Yaw (-1..1)", egui::Color32::from_rgb(230, 200, 60)),
                Series::new("Drone state (0..3)", egui::Color32::from_rgb(80, 200, 120)),
                Series::new("Sequence", egui::Color32::from_rgb(150, 150, 150)).hidden(),
                Series::new(
                    "Temperature (\u{00B0}C)",
                    egui::Color32::from_rgb(255, 140, 60),
                )
                .hidden(),
                Series::new("Round-trip (ms)", egui::Color32::from_rgb(120, 220, 220)).hidden(),
                Series::new(
                    "Avg round-trip (ms)",
                    egui::Color32::from_rgb(180, 120, 200),
                )
                .hidden(),
                Series::new("CPU load (%)", egui::Color32::from_rgb(255, 100, 180)).hidden(),
                Series::new("Accel X (g)", egui::Color32::from_rgb(240, 100, 100)),
                Series::new("Accel Y (g)", egui::Color32::from_rgb(100, 220, 120)),
                Series::new("Accel Z (g)", egui::Color32::from_rgb(100, 150, 240)),
                Series::new("Gyro X (dps)", egui::Color32::from_rgb(240, 170, 90)).hidden(),
                Series::new("Gyro Y (dps)", egui::Color32::from_rgb(170, 240, 170)).hidden(),
                Series::new("Gyro Z (dps)", egui::Color32::from_rgb(170, 170, 240)).hidden(),
                Series::new("Attitude roll (deg)", egui::Color32::from_rgb(255, 80, 80)),
                Series::new(
                    "Attitude pitch (deg)",
                    egui::Color32::from_rgb(180, 100, 255),
                ),
                Series::new("Demand roll (-1..1)", egui::Color32::from_rgb(255, 130, 90)),
                Series::new(
                    "Demand pitch (-1..1)",
                    egui::Color32::from_rgb(150, 130, 255),
                ),
                Series::new("Demand yaw (-1..1)", egui::Color32::from_rgb(255, 210, 90)),
                Series::new("Motor 1 (0..1)", egui::Color32::from_rgb(255, 120, 120)),
                Series::new("Motor 2 (0..1)", egui::Color32::from_rgb(120, 220, 140)),
                Series::new("Motor 3 (0..1)", egui::Color32::from_rgb(120, 180, 255)),
                Series::new("Motor 4 (0..1)", egui::Color32::from_rgb(230, 180, 80)),
                Series::new(
                    "Gyro X filtered (dps)",
                    egui::Color32::from_rgb(255, 210, 130),
                )
                .hidden(),
                Series::new(
                    "Gyro Y filtered (dps)",
                    egui::Color32::from_rgb(210, 255, 210),
                )
                .hidden(),
                Series::new(
                    "Gyro Z filtered (dps)",
                    egui::Color32::from_rgb(210, 210, 255),
                )
                .hidden(),
                Series::new(
                    "ESC temp (\u{00B0}C)",
                    egui::Color32::from_rgb(255, 160, 80),
                )
                .hidden(),
                Series::new("Pack voltage (V)", egui::Color32::from_rgb(120, 200, 100)).hidden(),
                Series::new("Pack current (A)", egui::Color32::from_rgb(230, 120, 120)).hidden(),
                Series::new("Consumed (mAh)", egui::Color32::from_rgb(180, 180, 120)).hidden(),
                Series::new("Motor 1 RPM", egui::Color32::from_rgb(255, 140, 140)).hidden(),
                Series::new("Motor 2 RPM", egui::Color32::from_rgb(140, 230, 160)).hidden(),
                Series::new("Motor 3 RPM", egui::Color32::from_rgb(140, 190, 255)).hidden(),
                Series::new("Motor 4 RPM", egui::Color32::from_rgb(240, 200, 110)).hidden(),
            ],
            last: None,
            remote_firmware_version: None,
            pending: VecDeque::new(),
            last_rtt_ms: None,
            avg_rtt_ms: None,
            gilrs: Gilrs::new().ok(),
            active_gamepad: None,
            gamepad_name: None,
            control_mode: ControlMode::Manual,
            params: ControlSystemParameters::default(),
            params_locked: false,
            last_control_seq: None,
            log_file: None,
            log_path: None,
            log_rows: 0,
            paused: false,
            attitude_view: AttitudeView::new(),
            attitude_texture: None,
        }
    }
}
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

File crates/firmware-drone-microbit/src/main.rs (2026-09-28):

#![no_std]
#![no_main]

//! Drone firmware entry point.
//!
//! Initialises the board and spawns the task set. Subsystem work — IMU
//! sampling, motor mixing, control loops, radio link — lives in tasks
//! spawned from here. Pure logic for those tasks lives in
//! `firmware-drone-core` per ADR 0007 / ADR 0009. Per-board wiring lives in
//! [`board`] per ADR 0010; tasks accept BSP wrapper types and never see
//! physical pins. System-wide state is owned and published by the
//! supervisor task ([`tasks::supervisor`]) per ADR 0013.

include!(concat!(env!("OUT_DIR"), "/version.rs"));
#[unsafe(link_section = ".buildconfig")]
#[used]
static VERSION: u32 = FIRMWARE_VERSION;

use defmt_rtt as _;
use embassy_executor::{InterruptExecutor, SendSpawner, Spawner};
use embassy_nrf::interrupt;
use embassy_nrf::interrupt::{InterruptExt, Priority};
use firmware_drone_shared::signals::cpu_load;

use firmware_drone_shared::spawn_shared_tasks;
// use firmware_drone_shared::{load_profiler, spawn_load_profiler}; //Not used for now
use firmware_types::CpuLoad;
use panic_probe as _;

mod board;
mod radio_link;
mod tasks;

static EXEC: InterruptExecutor = InterruptExecutor::new();
#[interrupt]
unsafe fn SWI0_EGU0() {
    unsafe { EXEC.on_interrupt() }
}

fn spawn_hardware_tasks(spawner: SendSpawner, board: board::Board) {
    spawner.must_spawn(tasks::status_led::status_led(board.status_led));
    spawner.must_spawn(tasks::remote_link::remote_link(board.radio));
    spawner.must_spawn(tasks::esc_telemetry::esc_telemetry(board.esc_telemetry));
    spawner.must_spawn(tasks::motor_controller::motor_controller(board.motors));
    spawner.must_spawn(tasks::temperature::temperature(board.temperature_sensor));
    spawner.must_spawn(tasks::imu::imu(board.imu));
    spawner.must_spawn(tasks::config_manager::config_manager(board.config_storage));
}

#[embassy_executor::main]
async fn main(_thread_mode_spawner: Spawner) {
    let board = board::Board::new();

    defmt::info!("firmware-drone-microbit on {}: boot ", board::NAME);

    // let calibration_baseline = load_profiler::calibrate();
    // Seed cpu_load so the telemetry aggregator never blocks on first-publish.
    // Harmless when the profiler runs (it overwrites this 0%); keeps telemetry
    // alive when the profiler is disabled.
    cpu_load::set(CpuLoad::from_percentage(0.0));

    interrupt::SWI0_EGU0.set_priority(Priority::P6);
    let high_priority_spawner = EXEC.start(interrupt::SWI0_EGU0);

    spawn_shared_tasks(high_priority_spawner, FIRMWARE_VERSION);
    spawn_hardware_tasks(high_priority_spawner, board);

    // spawn_load_profiler(_thread_mode_spawner, calibration_baseline);
}

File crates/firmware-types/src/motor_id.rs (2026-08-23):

use postcard::experimental::max_size::MaxSize;
use serde::{Deserialize, Serialize};

#[derive(Serialize, Deserialize, Clone, Copy, Debug, PartialEq, MaxSize, Default)]
#[cfg_attr(feature = "defmt", derive(defmt::Format))]
pub enum MotorID {
    #[default]
    None,
    Motor1,
    Motor2,
    Motor3,
    Motor4,
}

impl MotorID {
    pub fn increment_with_wraparound(&mut self) {
        *self = match self {
            MotorID::None => MotorID::Motor1,
            MotorID::Motor1 => MotorID::Motor2,
            MotorID::Motor2 => MotorID::Motor3,
            MotorID::Motor3 => MotorID::Motor4,
            MotorID::Motor4 => MotorID::Motor1,
        }
    }
}

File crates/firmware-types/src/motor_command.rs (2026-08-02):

use postcard::experimental::max_size::MaxSize;
use serde::{Deserialize, Serialize};

use crate::throttle_command::ThrottleCommand;

#[derive(Serialize, Deserialize, Clone, Copy, Debug, PartialEq, MaxSize)]
#[cfg_attr(feature = "defmt", derive(defmt::Format))]
pub struct MotorCommand {
    pub motor1: ThrottleCommand,
    pub motor2: ThrottleCommand,
    pub motor3: ThrottleCommand,
    pub motor4: ThrottleCommand,
}

impl MotorCommand {
    /// All four motors stopped.
    pub const ZERO: Self = Self {
        motor1: ThrottleCommand::ZERO,
        motor2: ThrottleCommand::ZERO,
        motor3: ThrottleCommand::ZERO,
        motor4: ThrottleCommand::ZERO,
    };
}

#[cfg(test)]
mod tests {
    use super::*;

    #[test]
    fn postcard_round_trip() {
        let original = MotorCommand {
            motor1: ThrottleCommand::from_normalised(0.75),
            motor2: ThrottleCommand::from_normalised(0.75),
            motor3: ThrottleCommand::from_normalised(0.75),
            motor4: ThrottleCommand::from_normalised(0.75),
        };
        let mut buf = [0u8; MotorCommand::POSTCARD_MAX_SIZE];
        let bytes = postcard::to_slice(&original, &mut buf).unwrap();
        let decoded: MotorCommand = postcard::from_bytes(bytes).unwrap();
        assert_eq!(original, decoded);
    }
}

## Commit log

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2026-05-24 feat(status): drive status LED from SystemState via Watch
    Replaces the fixed LED heartbeat with a SystemState-driven status indicator. A Watch<CriticalSectionRawMutex, SystemState, 8> publishes Booting/Idle/Fault; update_status_indicator subscribes and drives the on-board LED with distinct patterns (fast blink, heartbeat blip, strobe) via a pattern_for_state pure fn plus a play_pattern async driver that races a Timer against state changes.
    First use of the embassy-sync pub/sub primitives codified in ADR 0013. SystemState lives in firmware-drone (not -core) because embassy-sync is forbidden in -core by ADR 0009; ADR 0013 still needs amending to reflect this.
    main() cycles through the three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
    [main.rs]
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2026-05-25 feat(supervisor): introduce supervisor task as sole publisher of SystemState
    Moves SystemState and the STATUS Watch out of system_state.rs and into tasks/supervisor.rs alongside a new supervise task. Supervisor publishes Booting on startup, then for now cycles to Idle and Fault on a 5s timer as throwaway bring-up demo until real subsystems produce events.
    STATUS and set() are private to the module so the supervisor is the only publisher; consumers go through pub fn subscribe() -> StatusReceiver instead of touching the static directly. status_led.rs updated to use subscribe().
    main.rs no longer pokes SystemState directly; it just spawns the supervisor and status LED tasks. Docstring refresh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
    [main.rs]
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2026-05-27 feat(radio): basic drone->remote telemetry link over IEEE 802.15.4
    Drone TX task sends an incrementing u32 counter on channel 20; remote RX
    task receives, decodes, and logs count + LQI. Confirmed end-to-end with
    two micro:bit v2 boards.
    Switched from BLE 1Mbit mode to IEEE 802.15.4 to get hardware CRC gating
    on receive() and avoid the embassy BLE driver's multi-address acceptance
    default (RXADDRESSES enables addr0..4, only addr0 is programmed).
    Enabled HfclkSource::ExternalXtal in the board init -- required for the
    RADIO PLL to lock on-frequency for any 2.4 GHz operation.
    Closes #5.
    [main.rs]
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2026-05-27 feat(radio): bidirectional comm_link, drone echoes commands
    Remote drives the slot at ~100 Hz, sending an incrementing counter as a placeholder control payload. Drone echoes the received counter back as telemetry. Both sides use with_timeout(100ms) on receive() to avoid deadlocking on a lost frame.
    Replaces the one-way telemetry_tx / telemetry_rx tasks with a single comm_link task per crate.
    Refs #6
    [main.rs]
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2026-05-31 feat(motor): add motor BSP wrapper and demo task
    Adds L9110 H-bridge motor to the micro:bit v2 BSP (IA on P0.17, IB on P0.01) with forward/reverse/coast helpers. A new motor_controller task spins forward, coasts, then reverses on a fixed cycle as a bring-up demo.
    Scaffold only: GPIO toggling, not yet PWM. Direction-control is bench-useful for exercising both halves of the bridge, but a real quadcopter motor is single-direction (yaw via differential speed across CW/CCW props). API will collapse to set_throttle(duty) + coast() once PWM lands and ControlState carries real fields.
    [main.rs]
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2026-05-31 feat(motor): drive L9110 via PWM peripheral
    Replaces the raw GPIO toggling with the nRF52 PWM peripheral (PWM0, channel 0 on P0.17). IB is hard-wired to GND on the breadboard, so this is sign-magnitude PWM and direction is fixed forward (matches the eventual quadcopter use case where motors are single-direction; yaw comes from differential speed across CW/CCW props).
    Carrier is 16 kHz (Div1 prescaler, COUNTERTOP = 1000) — above audible, 1000-step resolution. Motors::set_throttle takes a percent 0..=100, clamps in range, and inverts to the nRF's counterintuitive 'duty = off ticks per period' convention. Widen-multiply-narrow (u32 inside the multiply) avoids u16 overflow that panicked debug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
    [main.rs]
2026-06-01 feat(types): end-to-end throttle control via PilotCommand + Throttle
    Replace the placeholder ControlState with PilotCommand, the first real
    remote->drone wire type. PilotCommand carries a Throttle newtype (f32
    clamped to 0..=1, NaN-safe) and a sequence_count (transport concern
    that will move to a Frame<T> envelope later).
    firmware-types is split into per-type modules (pilot_command, throttle,
    telemetry_state) and gains postcard round-trip tests as a host-only
    dev-dependency (uses cfg_attr(not(test), no_std) so the test harness
    can link std).
    Throttle implements Deserialize manually to route the inner f32 through
    from_normalised. Without this, garbage-but-postcard-valid bytes off the
    radio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
    [lib.rs]
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2026-06-05 feat(supervisor): extract failsafe state machine to firmware-drone-core
    Realises ADR 0017. The supervisor task in firmware-drone now wraps a
    pure Supervisor state machine living in firmware-drone-core, where it
    is host-testable per ADR 0015.
    Behaviour:
    - Initialising: never seen a PilotCommand. Tick -> output ZERO. First
    Command transitions to Armed.
    - Armed: Command updates throttle and resets the link-loss counter.
    Tick increments the counter; LINK_LOSS_TICKS (10 = 100 ms) without
    a Command transitions to Degraded and resets the ramp counter.
    - Degraded: Tick ramps throttle from previous_throttle towards zero
    over RAMP_TICKS (50 = 500 ms) using Throttle * f32. After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
    [supervisor_core.rs]
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2026-06-09 feat(remote): publish slider throttle via Watch, drone_link consumes it
    serial_link parses the ASCII line as f32, clamps via Throttle::from_normalised, and publishes to a new signals::THROTTLE_COMMAND Watch. drone_link replaces its self-incrementing throttle_counter with a subscription to the same Watch; .get().await on each tick takes the latest value (waits once for the first command, then non-blocking).
    [main.rs]
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2026-06-13 chore: signals refactor, telemetry wire types, RA fix
    - signals: per-signal modules under firmware-drone/src/signals/, replace
    the old tasks/pilot_command.rs (which was a signal masquerading as a
    task). Natural namespacing at call sites: signals::pilot_command::set,
    signals::motor_command::subscribe, etc. Same shape per file (static +
    Receiver alias + subscribe + set).
    - firmware-types: add Temperature newtype (f32 Celsius, custom Debug as
    "{:.2}°C") and extend TelemetryState with die_temperature.
    - BSP: wire the nRF52833 TEMP peripheral into firmware-drone's micro:bit
    v2 board so a future telemetry task can read die temperature.
    - remote: drone_link logs the received Telemet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
    [lib.rs, main.rs, motor_command.rs]
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2026-06-14 feat(drone): wire up TEMP peripheral and publish on telemetry signal
    Add a telemetry task that reads the nRF52833 die-temperature sensor
    once every 500 ms, converts the I30F2 fixed-point reading to f32 °C
    via Temperature::from_celsius, and publishes a TelemetryState on the
    telemetry Watch signal.
    remote_link now subscribes to the telemetry signal and ships the
    latest sample back to the remote in response to each PilotCommand
    instead of using a hard-coded placeholder.
    Also folds in a one-line rustfmt fix in tasks/supervisor.rs missed
    in the SystemState -> DroneState rename commit.
    [main.rs]
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2026-06-26 firmware-types: derive postcard MaxSize and size frame buffers from it
    A SerializeBufferFull panic (HardFault on no_std) was traced to a hand-picked [0u8; 32] buffer that no longer fit Telemetry after the cpu_load field was added. The buffer size and the struct definition had no compiler link, so the struct grew but the buffer did not.
    Derive postcard's MaxSize (experimental-derive) on Telemetry, GroundstationCommand, and all their constituent types. Export FRAME_MAX_SIZE_BYTES consts (COBS-padded worst case) and reference them at every TX/RX buffer site on both boards and the groundstation, so adding a wire field now grows every buffer at compile time.
    [lib.rs]
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2026-06-27 imu: bring up ICM-42688 over SPI with raw 6-axis read
    Add check_identity (WHO_AM_I 0x47), configure (PWR_MGMT0 low-noise), and read_all (12-byte burst from ACCEL_DATA_X1) plus an ImuError type to the micro:bit BSP. Add the imu task that detects, configures, then polls the sensor on a timer, and spawn it from main.
    read_all currently performs the burst without parsing the bytes; scaling raw i16 counts to g/dps and a firmware-types IMU sample type follow next.
    [main.rs]
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2026-06-27 groundstation: persist serial port and autoconnect on startup
    Enable eframe's persistence feature and store the configured port name
    in eframe storage, restoring it on launch and connecting immediately so
    the usual port no longer needs re-entering each run.
    [main.rs]
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2026-07-21 firmware-drone-core: add complementary-filter attitude estimator
    AttitudeEstimator per ADR 0022 section 7: a stateful gyro-predict / accel-correct complementary blend in degrees, seeded from the accelerometer on the first sample (no startup slew). Uses micromath's f32 trig on the target and std math in host tests. Host-tested for axis isolation, signs, convergence, and seeding, with inputs written in attitude units via an accel_for(roll, pitch) helper (the inverse of the accel correction; yaw-independent).
    [lib.rs]
2026-07-21 attitude: run estimator stage and publish it in telemetry
    Add the attitude_estimator task per ADR 0022 section 7: single publisher of an Attitude Watch, driving the firmware-drone-core AttitudeEstimator off the IMU Watch (changed()-paced) with a measured dt from Instant deltas. Pace the IMU task with a Ticker for a fixed cadence, and give its startup default a physically-valid level reading (1 g down -Z) so the estimator seeds cleanly. Add the attitude signal, wire it into the telemetry aggregator, and add the attitude field to Telemetry.
    [main.rs]
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2026-07-21 readme,doc: record attitude-estimator milestone
    Update the README Status with the complementary-filter attitude estimate (fused, seeded, measured dt, plotted on the ground station), refresh Next to the PID control law, and correct the now-stale motor pin reference to M1-M4. Append the dated 2026-07-21 progress entry covering the estimator, the NaN and telemetry-format bugs, and the mixer/wiring/IMU-orientation work.
    [main.rs]
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2026-07-22 control: close the loop with PD control law, mode toggle, and motor/demand telemetry
    Adds the ADR 0024 control law as a pure control_system function in firmware-drone-core (angle mode on roll/pitch, rate mode on yaw, derivative on the measured gyro, normalised errors so gains are dimensionless), host-tested for signs, damping, axis independence and saturation. A single-publisher control_system stage owns a ControllerDemand Watch; the supervisor now mixes that demand in Armed and overrides it in the failsafe states, replacing the raw-stick passthrough (its step signature and tests change accordingly).
    Adds a ControlMode { Manual, Stabilized } to GroundstationCommand and PilotCommand, toggled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
    [lib.rs, main.rs, motor_command.rs]
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2026-08-02 supervisor: add Disarmed state with two-phase arm/disarm gestures
    Introduce DroneState::Disarmed as the normal ground state between
    Initialising and Armed. The previous behaviour (arm on first command)
    is replaced with an explicit two-phase gesture sequence:
    Arm: throttle=0 + yaw-right held for 50 ticks, then yaw to centre
    Disarm: throttle=0 + yaw-left (immediate, no hold required)
    Degraded now recovers to Disarmed (not Armed) on a zero-throttle
    command, requiring the pilot to re-arm deliberately after any
    link-loss event.
    Also updates status_led for the new Disarmed variant, groundstation
    drone_state_code and telemetry display, and the MAX_THROTTLE cap
    added earlier this session.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
    [lib.rs, main.rs, supervisor_core.rs]
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2026-08-02 supervisor: auto-disarm after 100 s of zero throttle while Armed
    If the drone stays Armed with throttle below 0.1 for 100 seconds
    (MAX_NO_THROTTLE_TICKS), the supervisor transitions automatically to
    Disarmed and zeroes the motors. Any active throttle command (>= 0.1)
    resets the counter.
    Prevents the drone sitting indefinitely in Armed state during a bench
    session where the developer walks away or forgets to disarm.
    Two new unit tests cover the auto-disarm boundary and the counter
    reset on active throttle. The idle threshold is expressed as a named
    constant (MAX_NO_THROTTLE_TICKS) used by both the logic and the tests.
    [supervisor_core.rs]
2026-08-02 groundstation: update drone_state_code test for Disarmed variant
    The Disarmed state was added in the supervisor rework but the
    drone_state_codes_are_distinct_and_ordered test still had the old
    four-state values. Updated to match the current mapping.
    [lib.rs]
2026-08-02 control_system: accept ControlSystemParameters; add robust test suite
    The update() function now takes a ControlSystemParameters argument
    instead of reading module-level constants. Tests inject their own
    known-value parameters, decoupling test behaviour from production
    defaults entirely.
    63 unit tests now cover:
    - Exact numerical values for each P and D term in isolation,
    including hand-derived expected values in comments
    - P+D interaction for roll and pitch
    - Full-output tests combining stick, attitude error, and gyro rate
    - Saturation to +/-1.0 on all three axes (positive and negative)
    - Throttle passthrough and independence from attitude demands
    - Axis cross-contamination (roll stick d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
    [lib.rs]
2026-08-02 firmware-types,groundstation: use POSTCARD_MAX_SIZE in all round-trip tests
    Replaced every hardcoded buffer size in postcard round-trip tests with
    the TYPE::POSTCARD_MAX_SIZE constant derived from the MaxSize trait.
    Buffers encoding raw f32 values (garbage/NaN deserialization tests) are
    left as [0u8; 8] since they are not serialising the wrapper type.
    Also adds MaxSize derive to RemoteState, which was the only type in
    firmware-types missing it.
    [lib.rs, motor_command.rs]
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2026-08-02 mixer: return zero motors when throttle is zero
    The mixer now short-circuits to MotorCommand::ZERO whenever the
    throttle demand is zero. Zero throttle means the drone is on the
    ground; no attitude correction should spin any motor, and this
    cleanly prevents the disarm gesture (yaw-left at zero throttle)
    from producing spurious motor output.
    A new unit test verifies that non-zero roll/pitch/yaw demands are
    suppressed when throttle is zero.
    [lib.rs, mixer.rs]
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2026-08-05 refactor: Command enum replaces GroundstationCommand; RadioMessage on radio link
    Introduces three new types in firmware-types:
    PilotCommand { throttle, roll, pitch, yaw }
    -- sequence_count and control_mode removed; both are
    separate concerns at their respective layers.
    Command (enum)
    PilotCommand(PilotCommand)
    ControlModeUpdate(ControlMode)
    ControlSystemParameterUpdate(ControlSystemParameters)
    RadioMessage { sequence_count: u32, command: Command }
    -- the over-the-air packet; sequence_count lives here,
    not inside PilotCommand.
    GroundstationCommand is removed entirely.
    The remote drone_link task send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
    [lib.rs, main.rs]
2026-08-05 groundstation,firmware-drone: runtime control system parameter tuning
    Groundstation gains panel:
    - Add ControlSystemParameters field to App, initialised from Default.
    - Add collapsible 'Control System Parameters' panel with sliders for
    all 9 fields (kp/kd per axis, max angles and rates).
    - 'Send to drone' button dispatches Command::ControlSystemParameterUpdate
    to the serial thread.
    Mode toggle race fix:
    - Remove changed=true from the North (triangle) button handler. Sending
    a PilotCommand simultaneously with ControlModeUpdate overwrote the
    Watch before drone_link could send the mode change over radio.
    Firmware (drone):
    - control_system task now reads the control_system_parameter_up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
    [lib.rs, main.rs]
2026-08-05 control: gyro D-term low-pass filter and sane default gains
    Add a first-order PT1 filter (firmware-drone-core::filter, host-tested)
    and apply it to each gyro axis in the control-loop task before the D
    term, keeping motor-vibration noise out of the controller demand. The
    filter runs in the control-loop task, not the attitude estimator, so
    the estimator keeps its unfiltered gyro (filtering there would lag the
    attitude estimate). Cutoff 100 Hz against the confirmed 1 ms sensor
    cadence.
    Revise the default ControlSystemParameters to sane starting values:
    D-normalisation rate 20 -> 400 dps (the old value made the D term
    absurdly twitchy), yaw rate limit 20 -> 180 dps, kd 0.4 -> 0.05,
    kp_yaw 0 ->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
    [lib.rs]
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2026-08-07 radio: filter foreign frames by destination address; put RadioMessage on the wire
    Spurious control-mode flips to Manual were traced to foreign 802.15.4
    traffic on channel 20: the radio has no address filtering, so any frame
    that passes the hardware CRC (which proves integrity, not identity) was
    handed to postcard and could decode as a valid-but-unintended Command.
    A stray frame beginning with the ControlModeUpdate discriminant flipped
    the mode, and because the mode is a rarely-sent latched message, it
    stuck. The same hole exposed every Command variant, including
    PilotCommand (throttle/attitude), whenever the legitimate stream was
    not actively overwriting it.
    Fixes:
    - RadioMessage is now act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
    [lib.rs]
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2026-08-11 imu: add on-demand recalibration from ground station
    Zero IMU button in the ground station triggers a fresh accel/gyro offset capture on the drone (Disarmed only), so the craft can be re-levelled without a power cycle.
    Two layers had to be right. On the drone, the recalibrated offsets were captured into a shadowed let binding inside the if block and discarded, so the read loop kept using the startup offsets. On the remote, the reset was funnelled through the same command Watch as the ~100 Hz pilot stream, which clobbered the one-shot before the 10 ms relay sampled it; it now travels as a dedicated Signal that latches until the relay consumes it (per ADR 0013: single-observer event -> Signal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
    [main.rs]
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2026-08-12 imu: seed calibrate watch so read loop runs on cold boot
    imu_calibrate is a Watch whose only writers are remote_link (set true on reset) and the imu task (set false after calibrating). Nothing seeded it at boot, so on a fresh boot the read loop parked on the first imu_calibrate_receiver.get().await (which waits for first-ever publish) and never sampled the IMU - telemetry stayed frozen at the startup default until a Zero IMU press produced the first publish. Seed it to false after subscribe so get() returns immediately. Same first-publish class as the cpu_load seed; clarified that comment too.
    [main.rs]
2026-08-13 supervisor: split tick- and command-driven timeout thresholds
    The supervisor now ticks at 1 ms (1 kHz) so it no longer sub-samples the controller demand. Tick-counted thresholds were previously calibrated for a 10 ms tick, so link-loss and ramp timing were wrong at the new rate. Express all timeouts in milliseconds and derive tick counts from TICK_PERIOD_MS (tick-driven: link loss, ramp) and COMMAND_PERIOD_MS (command-driven: arm gesture, idle disarm), keeping gesture and idle counters locked to the remote command cadence rather than the tick rate. Remove ticks_to_ms, which conflated the two timebases.
    [supervisor_core.rs]
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2026-08-19 electrical: add v1 and v2 KiCad schematics
    v1: micro:bit-era wiring reference (nRF52833 + Blueson A1 4-in-1 ESC). v2: first-draft nRF5340 PCBA schematic (CopperPilot-generated) per ADR 0026 - Raytac MDBT53 module, native USB-C, SWD header, ICM-42688 on SPI, 4-in-1 ESC with telemetry + current sense, VBAT divider.
    v2 is an EARLY DRAFT, not fab-ready: known power-stage gaps (buck missing inductor / input+output caps / FB divider, boot cap on wrong node), sparse decoupling, and module/IMU pin maps still unverified against datasheets. Committed as a reviewable starting point.
    Transient KiCad files (.kicad_prl, .lck, backups) and the .copperpilot/ tool scratch dir are gitignored.
    [drone_fc.kicad_pcb, drone_fc.kicad_sch]
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2026-08-21 dshot: add host-tested frame encoder to firmware-drone-core
    Pure DShot frame construction (frame + throttle_frame + STOP/THROTTLE constants) with the standard non-inverted CRC. 6 tests: known-answer vectors computed independently (Betaflight algorithm) plus an exhaustive CRC round-trip over all 2048 values x both telemetry bits. Bit-timing/PWM expansion stays in the board layer.
    [dshot.rs, lib.rs]
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2026-08-21 dshot: add bidirectional DShot decode (GCR + eRPM)
    Pure receive-side decode for bidirectional DShot, host-tested and anchored to the BrushlessWhoop reference: bidir_frame (inverted CRC, 0x82C9 vector), gcr_decode (transition-decode + GCR quintet un-map, 0x82C6->0xD4BD6 + round-trip), erpm (uninverted-CRC check + exp/mantissa period -> electrical RPM, 200us->300000), and decode_erpm end-to-end. 6 new tests (12 total).
    Decode only: capturing the ESC's ~21-bit reply on the nRF (line turnaround + oversampling, no timer-DMA input capture on any nRF) is a board-specific research spike, parked for now. Original motivation (M4 diagnosis) already resolved by plain DShot; bidir's remaining value is R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
    [dshot.rs]
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2026-08-24 telemetry: split Telemetry into high-rate and low-rate frames
    Per ADR 0027, replace the single Telemetry type with a tagged TelemetryFrame { HighRate, LowRate } enum so the new ESC telemetry fits under the 802.15.4 packet ceiling. The high-rate frame carries the flight-critical fields at ~100 Hz (raw IMU plus filtered gyro, attitude, pilot_command as the RTT echo, controller demand, motor command, drone state) and drops the duplicated accelerometer. The low-rate frame carries cpu_load, control_mode, chip temperature, ESC telemetry and the drone's active control parameters echoed for ground-truth logging.
    Rewire the drone/remote telemetry signals, radio links and aggregator onto TelemetryFra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
    [lib.rs, telemetry_frame.rs, telemetry_frame_high_rate.rs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]
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2026-08-24 groundstation: right-align telemetry values, drop forced + sign
    Render each telemetry-table value right-justified in a fixed-width monospace field so a fluctuating reading's digits stay put instead of jittering. Drop the forced + on bipolar channels now that the fixed-width field keeps alignment stable regardless of sign.
    [main.rs]
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2026-08-24 groundstation: display ESC telemetry and group the table into boxed columns
    Surface the low-rate ESC telemetry (ESC temperature, pack voltage and current, consumed mAh, per-motor RPM) as new plot series, table rows and TSV columns; the analyzer is header-driven so it keeps working unchanged. Reorganise the telemetry readout from a flat wrapped list into labelled, fixed-width category boxes stacked in vertical columns (System/Pilot command/Attitude, Accelerometer/Gyro, Controller demand/Motor command, ESC power), so related metrics group together and the boxes align without overflowing off-screen.
    [main.rs]
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
